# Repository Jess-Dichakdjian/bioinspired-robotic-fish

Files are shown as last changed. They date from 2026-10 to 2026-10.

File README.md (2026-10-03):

# PHOENIX — Bioinspired Robotic Fish

**Programmable Hybrid Oceanic Entity: Networked Inertial Explorer**

A physically built bioinspired robotic fish based on **Atlantic-mackerel carangiform locomotion**, combining a segmented mechanically actuated tail, waterproof 3D-printed structure, embedded sensing, closed-loop propulsion control, active head stabilization, hydrodynamic modelling, and experimental in-water validation.

> **Status:** Completed academic team project  
> **Team:** Abdelrhman Amgad, Ahmed Mounir, Giulia Di Sipio, Tony Al Helou, Jessica Dichakdjian  
> **Course:** Bioinspired Robotics Lab — Politecnico di Milano  
> **Academic Year:** 2025–2026

---

## At a Glance

| | |
|---|---|
| **Robot type** | Bioinspired robotic fish |
| **Biological inspiration** | Atlantic mackerel |
| **Locomotion** | Body-Caudal Fin (BCF), carangiform |
| **Propulsion** | Single DC motor driving a segmented tail |
| **Steering / stabilization** | Servo-actuated head |
| **Controller** | Arduino Nano |
| **Feedback** | Motor encoder + MPU-9250 IMU |
| **Control** | PID propulsion-speed loop + head stabilization |
| **Manufacturing** | SolidWorks, 3D printing, silicone molding, bent steel shaft |
| **Validation** | Dry tests, waterproofing, buoyancy, thrust measurement, swimming |
| **Final demonstrated speed** | 0.33 m/s at 1.5 Hz |
| **Normalized speed** | 0.73 body lengths/s |

---

# Project Overview

The goal of PHOENIX was to design, manufacture, integrate, and experimentally validate a **waterproof robotic fish capable of sustained straight-line swimming**.

The robot was inspired by Atlantic-mackerel propulsion and simplified into a practical electromechanical architecture suitable for rapid prototyping.

The complete engineering workflow covered:

```text
Biological Locomotion Study
            ↓
Kinematics & Hydrodynamic Modelling
            ↓
Mechanical Architecture
            ↓
CAD & Component Selection
            ↓
Manufacturing & Silicone Fabrication
            ↓
Electronics Integration
            ↓
Embedded Control
            ↓
Waterproofing & Buoyancy
            ↓
Experimental Validation
```

The final prototype successfully generated forward propulsion in water and integrated the mechanical, electronic, sensing, and control subsystems into a functional swimming robot.

---

# My Contributions

This was a **five-person team project**.

My contributions were concentrated in mechanical design, physical fabrication, integration, component selection, and experimental testing.

## Mechanical Design

I worked on the **mechanical design and CAD of the tail system**, including the segmented structure used to reproduce the required oscillatory swimming motion.

I also contributed to development of the propulsion mechanism that converts motor rotation into lateral tail oscillation.

## Manufacturing & Integration

My hands-on work included:

- 3D printing robot components
- mechanical assembly
- silicone molding
- manual bending of the drive shaft
- integration of the tail mechanism
- sealing and waterproofing
- general system integration and troubleshooting

## Electronics & Component Selection

I contributed to selecting and integrating components that had to satisfy two competing requirements:

- fit within the limited internal volume of the fish
- provide sufficient performance for underwater propulsion and sensing

I also assisted with the general electronics integration process.

## Experimental Testing

I participated in the full test programme, including:

- dry mechanical validation
- waterproofing tests
- buoyancy checks
- thrust measurement
- initial swimming trials
- final swimming validation

The embedded software, electronics, and system architecture were developed collaboratively by the team. Code in this repository is therefore presented as **team project code**, not as a claim of sole individual authorship.

---

# Biological Inspiration

PHOENIX was inspired by the **Atlantic mackerel**, selected for its efficient high-speed swimming characteristics.

The robot reproduces a simplified form of **Body-Caudal Fin carangiform locomotion**.

In carangiform swimming:

- most of the body remains relatively rigid
- oscillation is concentrated in the posterior section
- a travelling lateral wave propagates toward the tail
- the caudal fin generates the dominant propulsive force
- passive fins improve stability

---

# Mechanical Architecture

The robot consists of:

```text
Servo-Actuated Head
        ↓
Rigid Main Body
        ↓
Segmented Tail
        ↓
Active Tail Link
        ↓
Rigid Caudal Fin
```

The biological morphology was simplified into a mechanically realizable multi-link system while retaining the essential posterior-body oscillation required for carangiform propulsion.

### Final CAD Assembly

[▶ View final CAD assembly](P.H.O.E.N.I.X_Media/P.H.O.E.N.I.X_CAD/final_cad_assembly.mp4)

---

# Tail Propulsion Mechanism

The propulsion system uses a modified **Scotch-yoke / bent-shaft mechanism**.

```text
DC Motor
   ↓
Bent Shaft
   ↓
Oscillating Flapper / Linkage
   ↓
Segmented Tail Motion
   ↓
Caudal Fin
   ↓
Forward Thrust
```

A single rotating motor input is converted into lateral oscillation.

Mechanical stops and shaft geometry define the permitted angular motion of the tail links.

The architecture provides:

- high tail-beat frequency
- periodic oscillation
- single-actuator propulsion
- mechanically constrained link amplitudes

### Tail Mechanism

[▶ View tail mechanism](P.H.O.E.N.I.X_Media/P.H.O.E.N.I.X_CAD/tail_mechanism.mp4)

---

# Active Head Steering

The head is independently actuated by a servo motor.

Its role is to:

- compensate for heading drift
- improve straight-line stability
- provide active steering authority

The servo command is generated using IMU feedback in the stabilization loop.

---

# Fin Design

The robot includes:

- caudal fin
- dorsal fin
- anal fin
- two lateral fins

The **caudal fin** generates the primary propulsion force.

The remaining fins improve passive roll, yaw, and directional stability.

---

# Materials & Fabrication

The prototype combined rigid and compliant materials.

| Material | Application |
|---|---|
| PLA | External body and fins |
| ABS | Motor supports |
| Low-carbon steel | Bent drive shaft |
| Carbon fiber | Internal spar |
| Brass | Motor coupling |
| Ecoflex 00-10 | Tail and neck silicone sleeves |
| Elastic membrane | Additional waterproofing |

The manufacturing workflow included:

```text
CAD Design
    ↓
3D Printing
    ↓
Silicone Mold Fabrication
    ↓
Ecoflex Casting
    ↓
Steel Shaft Bending
    ↓
Mechanical Assembly
    ↓
Electronics Packaging
    ↓
Waterproofing
```

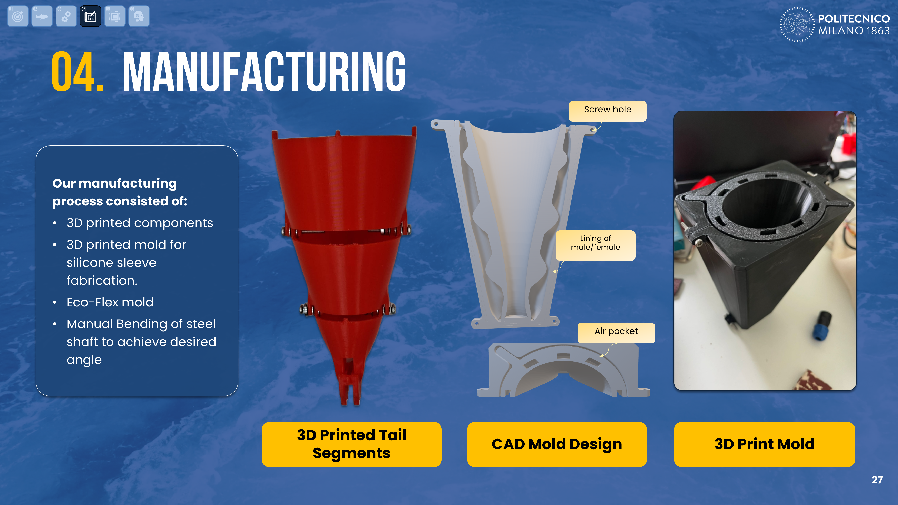
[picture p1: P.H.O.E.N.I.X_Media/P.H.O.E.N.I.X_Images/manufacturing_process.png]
Manufacturing process


---

# Waterproofing

Because the robot operates submerged, waterproofing was a major engineering constraint.

The final design used:

- enclosed electronics compartments
- silicone sleeves
- silicone adhesive
- protected shaft and cable interfaces
- iterative leak testing
- sealed mechanical interfaces

### Immersion / Leak Test

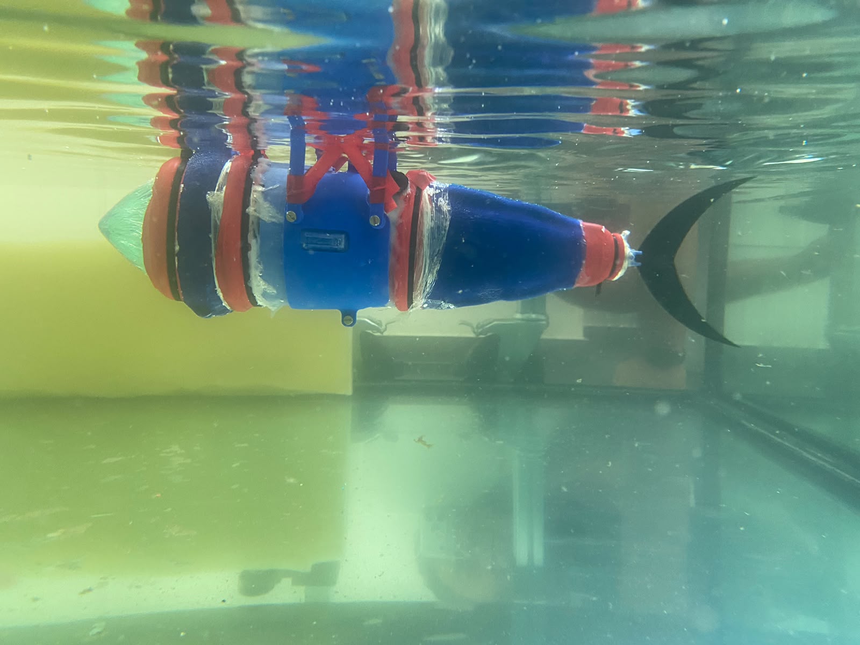
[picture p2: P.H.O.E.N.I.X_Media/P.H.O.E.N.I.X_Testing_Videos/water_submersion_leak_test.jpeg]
Water submersion test


---

# Buoyancy

The fish was tuned toward near-neutral buoyancy using:

- internal air volume
- component placement
- body mass
- steel ballast

Buoyancy was validated experimentally before powered swimming.

---

# Electronics Architecture

The embedded system includes:

- Arduino Nano
- brushed DC geared motor
- integrated encoder
- DRV8871 motor driver
- MPU-9250 IMU
- steering servo
- battery
- Hall-effect magnetic input

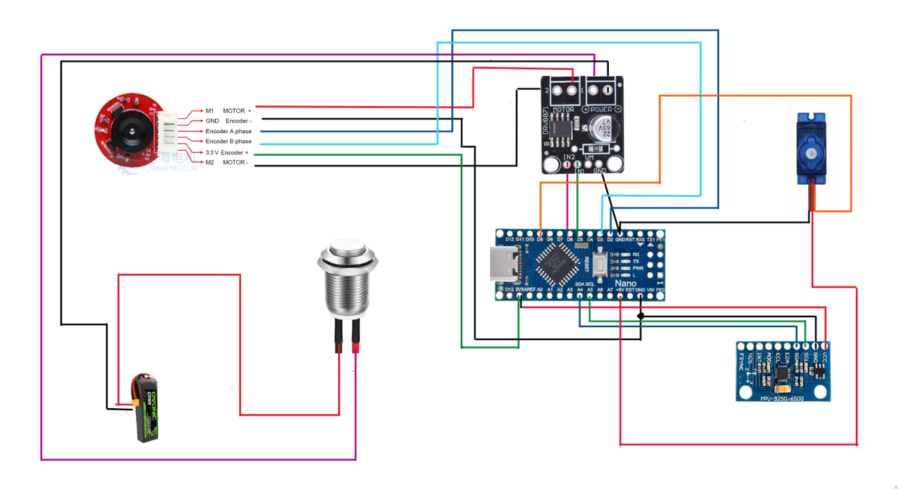
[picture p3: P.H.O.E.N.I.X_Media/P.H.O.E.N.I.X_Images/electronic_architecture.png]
Electronic architecture


### Internal Electronics Packaging

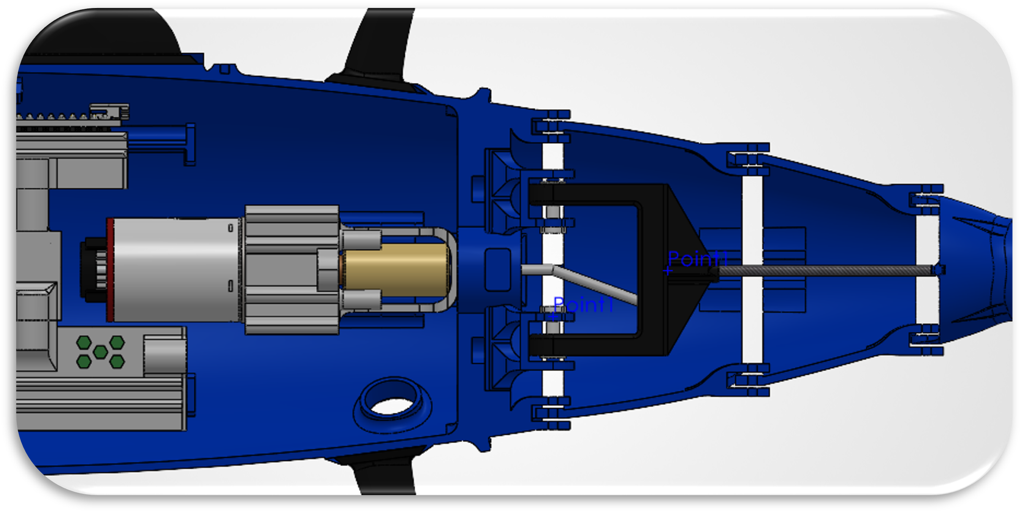
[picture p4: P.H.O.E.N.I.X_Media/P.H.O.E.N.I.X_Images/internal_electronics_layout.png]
Internal electronics layout


Component packaging was a significant design constraint because the electronics had to fit inside the waterproof body while preserving suitable mass distribution and buoyancy.

---

# Software Architecture

The embedded software contains several functional modules:

```text
Mode Manager
      ↓
Propulsion Controller
      ↓
PID Speed Control
      ↓
Motor Driver
      ↓
DC Motor
      ↑
Encoder Feedback

MPU-9250
      ↓
Drift Estimation
      ↓
Head Stabilization
      ↓
Servo Motor
```

The system supports:

- OFF mode
- normal swimming mode
- fast swimming mode
- soft-start ramp
- encoder-based PID speed control
- IMU-based drift estimation
- servo head correction
- magnetic external control

---

# Propulsion Control

Motor speed is regulated using encoder feedback:

```text
Target Frequency
      ↓
Soft-Start Ramp
      ↓
PID Controller
      ↓
PWM Command
      ↓
DRV8871
      ↓
DC Motor
      ↑
Encoder Feedback
```

Primary operating points were approximately:

```text
Normal mode: 1.5 Hz
Fast mode:   3.0 Hz
```

The soft-start stage reduces sudden mechanical loading during startup.

---

# Head Stabilization

The MPU-9250 gyroscope measures body rotation.

```text
Gyroscope
    ↓
Drift Estimate
    ↓
Servo Mapping
    ↓
Head Correction
```

The propulsion loop and the head-stabilization loop operate independently.

---

# Arduino Software

The final integrated robot software is available at:

```text
P.H.O.E.N.I.X_Software/
└── PHOENIX_CODE/
    └── PHOENIX_CODE.ino
```

The repository also preserves intermediate test software:

```text
Software_Used_During_Testing/
├── Calibration_Code/
├── Main_Logic_withPID/
└── Ramp_up/
```

These files document the development process rather than showing only the final result.

The project also contains a separate servo test program:

```text
P.H.O.E.N.I.X_Software/Servo/Servo.ino
```

---

# Kinematics & Hydrodynamic Modelling

The fish was represented using a rigid main body and a segmented multi-link tail.

The modelling work included:

- prescribed joint motion
- tail centerline reconstruction
- equivalent tail geometry
- hydrodynamic force estimation
- thrust prediction
- power estimation
- propulsive efficiency
- actuator sizing

A slender-body / added-mass-based hydrodynamic model was used to approximate the forces generated by the active tail.

The MATLAB model is available at:

```text
P.H.O.E.N.I.X_Software/
└── Dynamics Simulation/
    └── Dynamics_final.m
```

---

# Motor Sizing

The propulsion actuator was sized using:

- predicted hydrodynamic power
- required hydrodynamic torque
- drivetrain/mechanical efficiency
- silicone deformation losses
- safety margin

The final propulsion motor was a:

```text
ChiHai CHR-GM25-370ABHL
12 V brushed DC geared motor
350 RPM
Integrated incremental encoder
```

---

# Experimental Validation

Testing followed a progressive process to avoid exposing the final electronics to water before the mechanical system had been validated.

---

## 1. Dry Motion Test

The first validation stage checked:

- motor-driven tail actuation
- linkage motion through the silicone sleeve
- normal-speed mode
- fast-speed mode
- servo/head movement

[▶ Watch dry motion test](P.H.O.E.N.I.X_Media/P.H.O.E.N.I.X_Testing_Videos/dry_motion_test.mp4)

The expected oscillatory tail motion was achieved before water testing.

---

## 2. Waterproofing & Buoyancy

The robot was then submerged to validate:

- sealing
- sleeve integrity
- electronics isolation
- floating posture
- absence of visible leakage

This stage confirmed that the prototype was ready for powered aquatic testing.

---

## 3. Initial In-Water Trial

The first swimming test was performed without the final stabilizing fins.

[▶ Watch initial water trial](P.H.O.E.N.I.X_Media/P.H.O.E.N.I.X_Testing_Videos/initial_water_trial.mp4)

The robot generated forward propulsion, but directional stability was limited.

Observed roll and yaw motivated the addition of passive stabilizing fins before the final test.

---

# Thrust Measurement

A load-cell test was used to compare theoretical and experimental propulsion.

At **1.5 Hz**:

```text
Theoretical peak hydrodynamic thrust ≈ 1.20 N
Experimental peak dynamic load      ≈ 1.38 N
Difference                          ≈ 15%
```

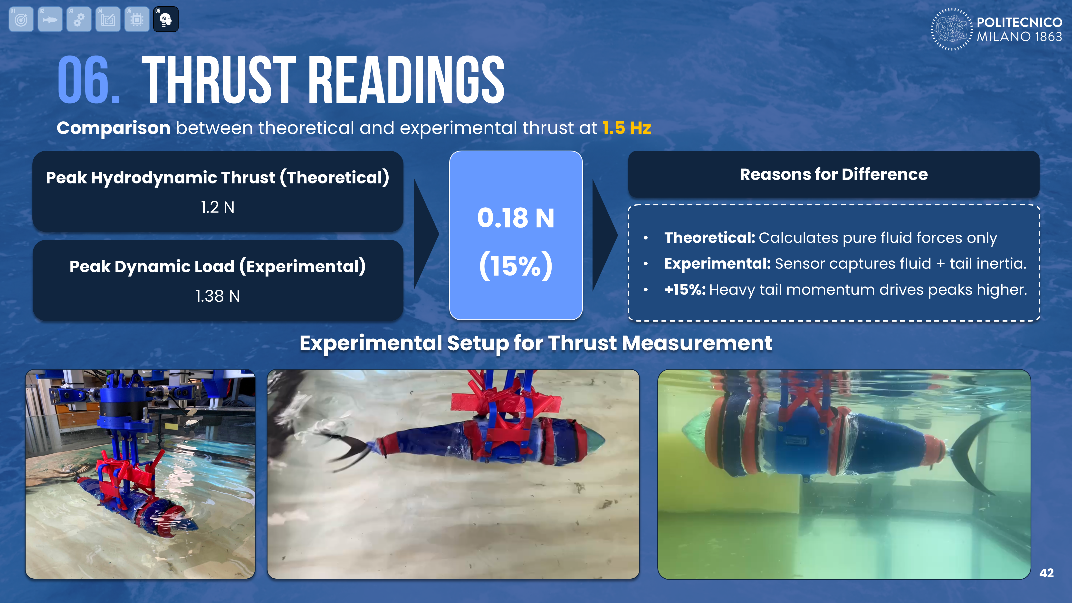
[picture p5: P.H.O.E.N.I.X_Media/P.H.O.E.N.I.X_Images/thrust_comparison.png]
Theoretical vs experimental thrust


### Physical Test

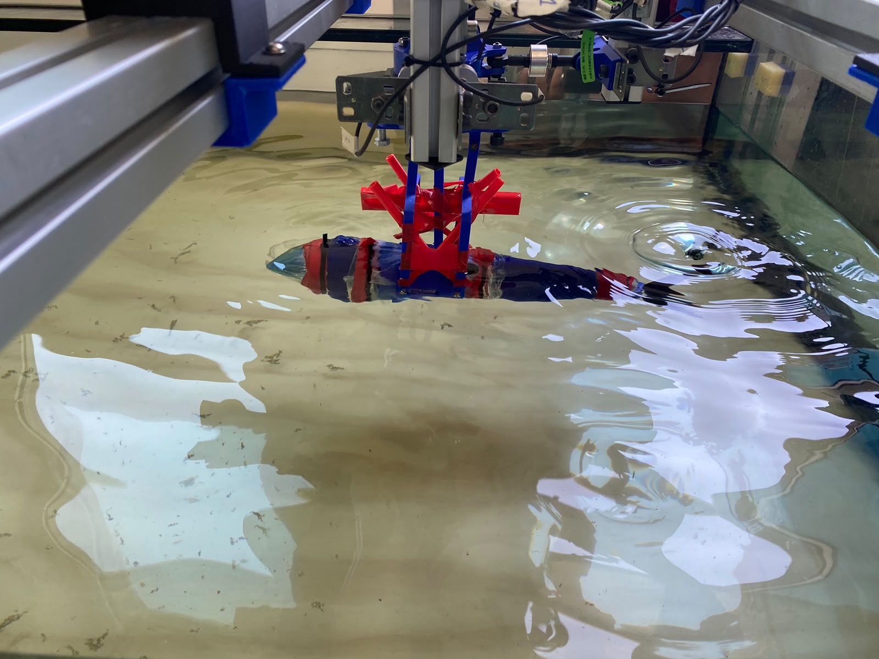
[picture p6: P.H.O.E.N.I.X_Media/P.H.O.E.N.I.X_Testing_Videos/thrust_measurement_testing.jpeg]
Thrust measurement setup


[▶ Watch thrust measurement](P.H.O.E.N.I.X_Media/P.H.O.E.N.I.X_Testing_Videos/thrust_measurement_testing.mp4)

The experimental value includes effects that are not fully represented in the simplified theoretical model, including:

- tail inertia
- linkage losses
- turbulence
- structural flexibility
- non-ideal tail motion

---

# Final Swimming Test

The complete robot was tested in water with the final stabilization configuration.

At:

```text
Tail frequency: 1.5 Hz
```

the prototype achieved:

```text
Swimming speed: 0.33 m/s
Normalized speed: 0.73 body lengths/s
```

[▶ Watch full swimming test](P.H.O.E.N.I.X_Media/P.H.O.E.N.I.X_Testing_Videos/full_swimming_test.mp4)

An additional underwater view of the propulsion behaviour is available here:

[▶ Underwater propulsion view](P.H.O.E.N.I.X_Media/P.H.O.E.N.I.X_Testing_Videos/underwater_pov_swimming_thurst_tester.mp4)

---

# Final Course Competition

At the end of the project, the teams participated in a class swimming comparison.

Each group performed a single tank-traversal trial, with performance evaluated using swimming time and body-length normalization.

**PHOENIX recorded the fastest body-length-normalized traversal among the participating group robots in that single-run comparison.**

Because each team performed only one trial, this result is presented as a **course demonstration result**, not as a statistically validated benchmark.

[▶ Watch competition swim](P.H.O.E.N.I.X_Media/competition_final_swim.mp4)

---

# Engineering Iteration

The project archive intentionally preserves earlier design iterations.

The mechanical system evolved through changes related to:

- friction
- tail geometry
- waterproofing
- electronics packaging
- assembly access
- directional stability
- actuator integration

This repository therefore documents not just the final robot, but also the engineering process used to reach it.

---

# Repository Structure

```text
bioinspired-robotic-fish/
│
├── README.md
│
├── P.H.O.E.N.I.X_CAD/
│   ├── P.H.O.E.N.I.X.SLDASM
│   ├── Tail_Links_Assembly.SLDASM
│   ├── Body_V3.SLDPRT
│   ├── Link3.SLDPRT
│   ├── Link4.SLDPRT
│   ├── Link5_V3.SLDPRT
│   └── ...
│
├── P.H.O.E.N.I.X_Software/
│   ├── Dynamics Simulation/
│   │   └── Dynamics_final.m
│   │
│   ├── PHOENIX_CODE/
│   │   └── PHOENIX_CODE.ino
│   │
│   ├── Servo/
│   │   └── Servo.ino
│   │
│   └── Software_Used_During_Testing/
│       ├── Calibration_Code/
│       ├── Main_Logic_withPID/
│       └── Ramp_up/
│
├── P.H.O.E.N.I.X_Media/
│   ├── P.H.O.E.N.I.X_CAD/
│   ├── P.H.O.E.N.I.X_Images/
│   ├── P.H.O.E.N.I.X_Testing_Videos/
│   └── competition_final_swim.mp4
│
└── P.H.O.E.N.I.X_Doc/
    └── Bioinspired Robotics Lab Project Presentation_vf-compressed.pdf
```

---

# Limitations

The prototype achieved the primary project objective, but several limitations remain:

- swimming experiments were performed in a controlled tank environment
- the hydrodynamic model uses simplifying assumptions
- tail-fluid interaction is difficult to represent exactly
- long-duration waterproofing was not characterized
- steering and trajectory tracking remain relatively simple
- full autonomous navigation was outside the project scope
- the final competition comparison used only one trial per team

---

# Future Work

Potential improvements include:

- vision-based navigation
- closed-loop trajectory tracking
- active depth control
- optimized tail geometry
- improved hydrodynamic modelling
- improved waterproofing durability
- reduced drivetrain losses
- energy-efficiency analysis
- longer-duration endurance tests
- autonomous underwater navigation

---

# Skills Demonstrated

This project provides evidence of experience in:

- bioinspired robotics
- underwater robotics
- robotic locomotion
- mechatronics
- SolidWorks
- CAD
- 3D printing
- silicone molding
- waterproof mechanical design
- electromechanical integration
- actuator selection
- Arduino
- embedded systems
- PID control
- encoder feedback
- IMU sensing
- servo control
- MATLAB
- hydrodynamic modelling
- dynamics
- motor sizing
- experimental robotics
- thrust measurement
- iterative prototyping
- system integration
- hardware testing

---

# Team Work & Attribution

PHOENIX was developed as a **five-person academic team project**.

The robot, software, CAD, electronics, and experimental programme were developed collaboratively.

My primary contributions were:

- mechanical CAD and design of the tail system
- development and physical implementation of the propulsion mechanism
- 3D printing
- silicone molding
- shaft bending
- mechanical assembly
- sealing and waterproofing
- electronics/component selection and packaging
- system integration
- experimental testing

Software and system-level code are presented as team project work unless explicitly stated otherwise.

---

# Project Status

✅ **Completed functional underwater robotic prototype**

The final system demonstrated:

- waterproof operation
- stable deployment
- oscillatory tail propulsion
- closed-loop propulsion-speed control
- IMU-based head stabilization
- experimentally measured thrust
- straight-line swimming
- 0.33 m/s swimming speed at 1.5 Hz
- successful final course competition run

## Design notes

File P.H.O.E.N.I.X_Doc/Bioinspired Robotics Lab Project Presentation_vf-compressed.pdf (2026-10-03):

# P.H.O.E.N.I

.X

Abdelrhman Amgad, Ahmed Mounir, Giulia Di Sipio, Tony Al Helou, Jessica Dichakdjian

Bioinspired Robotics Lab | A.Y. 2025-26 Professor Giovanni Bianchi

# Programmable Hybrid Oceanic Entity: Networked Inertial explorer

1

# OUTLINE

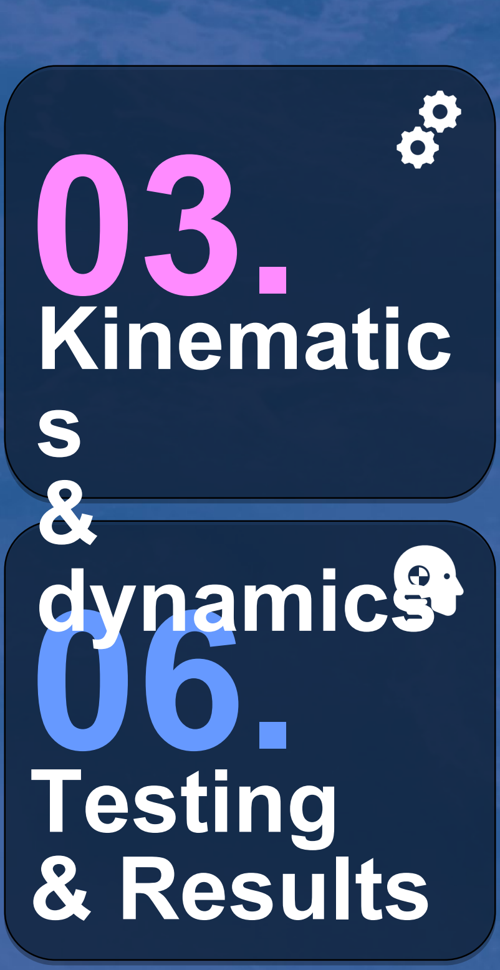
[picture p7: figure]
06. Testing & Results; 03. Kinematic s&; dynamics

2

05.

# Electroni

cs

# & control

04.

# Robotic Fish Design

02.

# Bioinspir ation

01.

# introduct ion

01.
introduct ion | 3

Bioinspired Design | Testing & Validation | Results and Discussion

# Motivation of the Project

o

## 1. Goal

### Design and fabricate a prototype of a waterproof, buoyant robotic fish capable of sustained straight-line swimming

- Replicate high-speed and efficient propulsion of
Atlantic Mackerel fish
- Carangiform (Body-Caudal Fin) locomotion
- Submerge in a controlled aquatic environment
- Experimentally test the
robot's swimming speed
and thrust generation
- Compare experimental
results with theoretical
models
- Identify hydrodynamic and structural design limitations

4

01 | 02 | 03 | 04 | 05 | 06

# o1Why a Robotic Fish?

A bioinspired robotic fish supports marine research and inspection in a non-intrusive manner

5

- Minimal acoustic and wake signatures compared to
- Navigate and inspect environments and infrastructure
- Monitor coral reefs, water quality, pipelines
- Support marine research and aquaculture operations without

# Design Constraints & Requirements

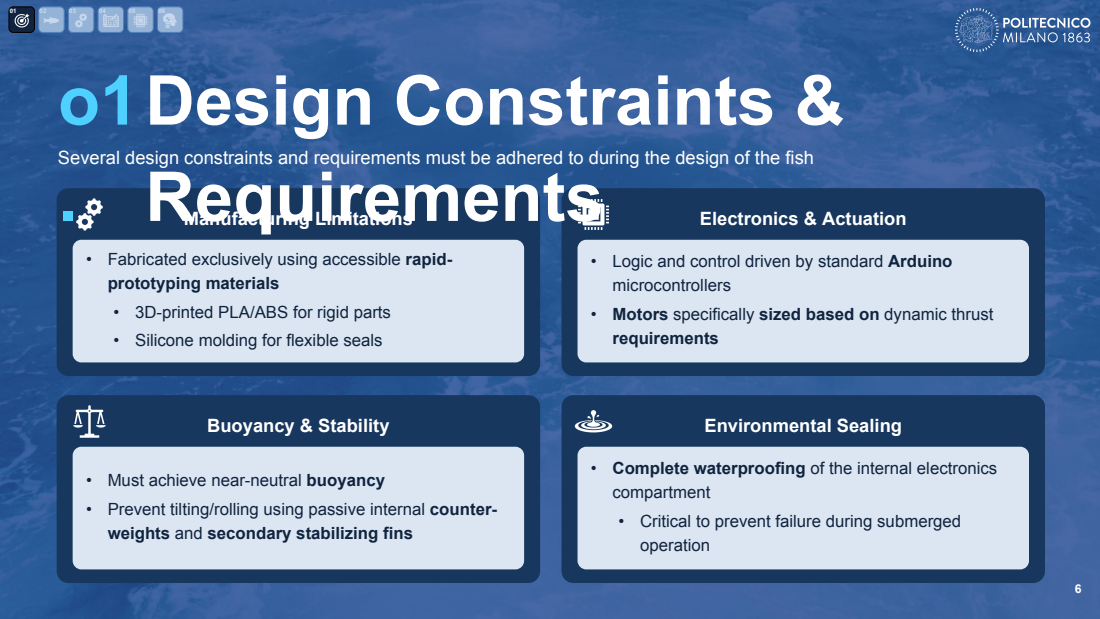
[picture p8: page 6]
Manufacturing Limitations; Electronics & Actuation; Buoyancy & Stability; Environmental Sealing

Several design constraints and requirements must be adhered to during the design of the fish

• Fabricated exclusively using accessible rapid-
prototyping materials
• 3D-printed PLA/ABS for rigid parts
• Silicone molding for flexible seals

• Logic and control driven by standard Arduino
microcontrollers
• Motors specifically sized based on dynamic thrust
requirements

• Complete waterproofing of the internal electronics
compartment
• Critical to prevent failure during submerged
operation

• Must achieve near-neutral buoyancy
• Prevent tilting/rolling using passive internal counter-
weights and secondary stabilizing fins

02.
bioinspiratio n | 7

# Biological Inspiration of Robot

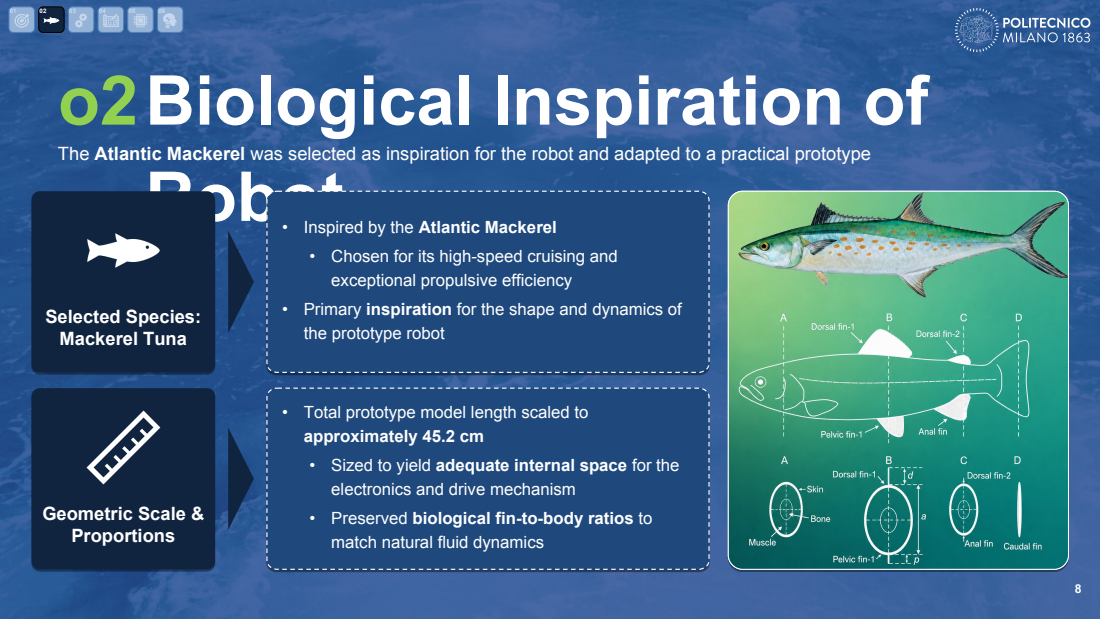
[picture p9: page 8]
Selected Species: Mackerel Tuna; Geometric Scale & Proportions

The Atlantic Mackerel was selected as inspiration for the robot and adapted to a practical prototype

• Inspired by the Atlantic Mackerel
• Chosen for its high-speed cruising and
exceptional propulsive efficiency
• Primary inspiration for the shape and dynamics of
the prototype robot

• Total prototype model length scaled to
approximately 45.2 cm
• Sized to yield adequate internal space for the
electronics and drive mechanism
• Preserved biological fin-to-body ratios to
match natural fluid dynamics

9

# o2Locomotion Strategy

The fish utilizes a BCF Carangiform locomotion strategy for thrust generation, steering, and stability
- Synchronized action of posterior body undulations and tail movements
- Combines side-to-side sweeping of fin (heaving) with angular twisting (pitching)
- Pushes water backward to generate a positive net forward force and overcome hydrodynamic drag
- Bending motion is strictly localized to the posterior section of the fish
- Kinematic wave actions are confined to the rear third of the total body length
- This tail structure and movement strategy generates a smooth traveling wave
- Stiff, lunate-shaped caudal fin designed for optimized thrust transmission
- Passive secondary fins handle orientation (pectoral) and lateral stability control (dorsal/pelvic)
Thrust Generation | Undulatory Wave
Profile | Hydrodynamic Fins

Body-Caudal Fin (BCF) Carangiform Swimming

10

# From Biology to

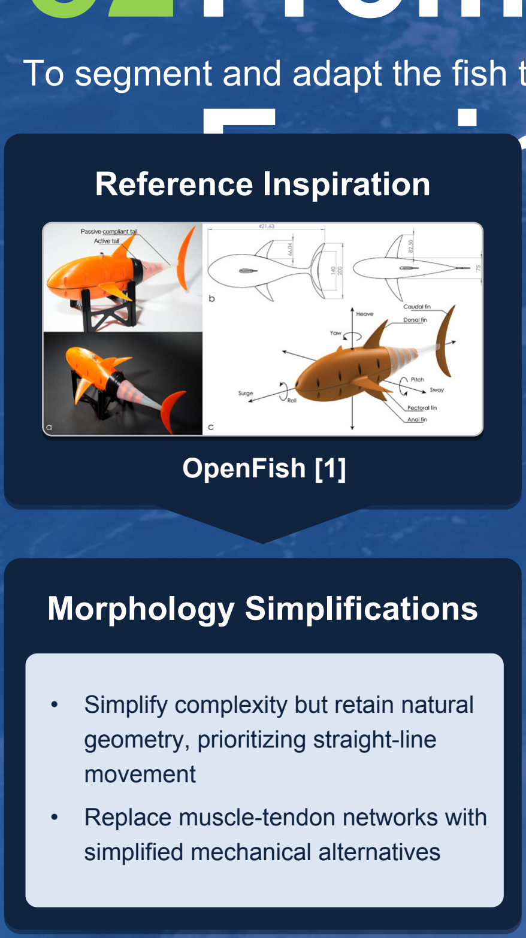
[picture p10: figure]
Morphology Simplifications; Reference Inspiration; geometry, prioritizing straight-line movement • Replace muscle-tendon networks with simplified mechanical alternatives; OpenFish [1]

# Engineering

o2

To segment and adapt the fish to a robot, several simplifications were made to the morphology of the fish Structure Segmentation

Static Body
Rigid central compartment containing and protecting the primary electronics, Arduino, and battery
Passive Tail
Flexible, segmented multi-link jointed portion of the tail propagating the undulatory traveling wave
Active Tail
Final tail linkage connected directly to the main motor drive mechanism to receive active mechanical power
Rigid Caudal Fin
Solid lunate-shaped profile attached to the active tail segment to for force transmission and forward propulsion
- Simplify complexity but retain natural

Active Head
Rigid section at anterior tip driven by an independent servo motor to handle active steering and heading control

# o2Actuation Inspiration

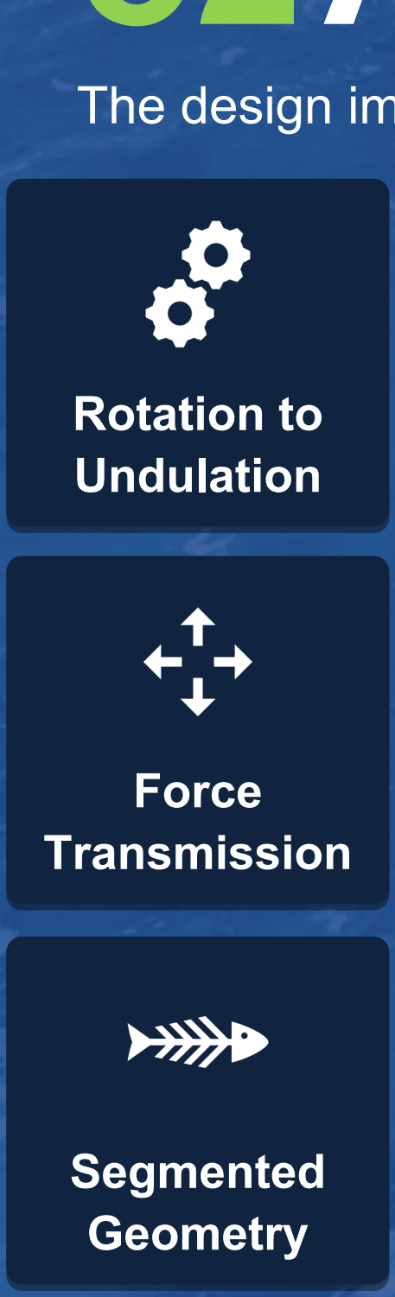
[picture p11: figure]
Segmented Geometry; Rotation to Undulation; Transmission

The design implements a linkage mechanism to convert a motor's rotation into a propulsive traveling wave

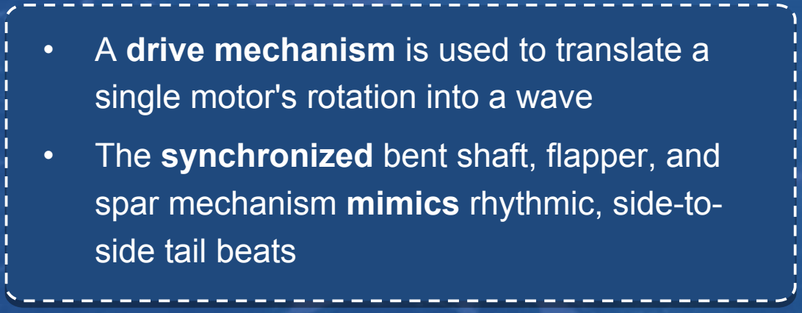
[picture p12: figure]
single motor's rotation into a wave; spar mechanism mimics rhythmic, side-to- side tail beats
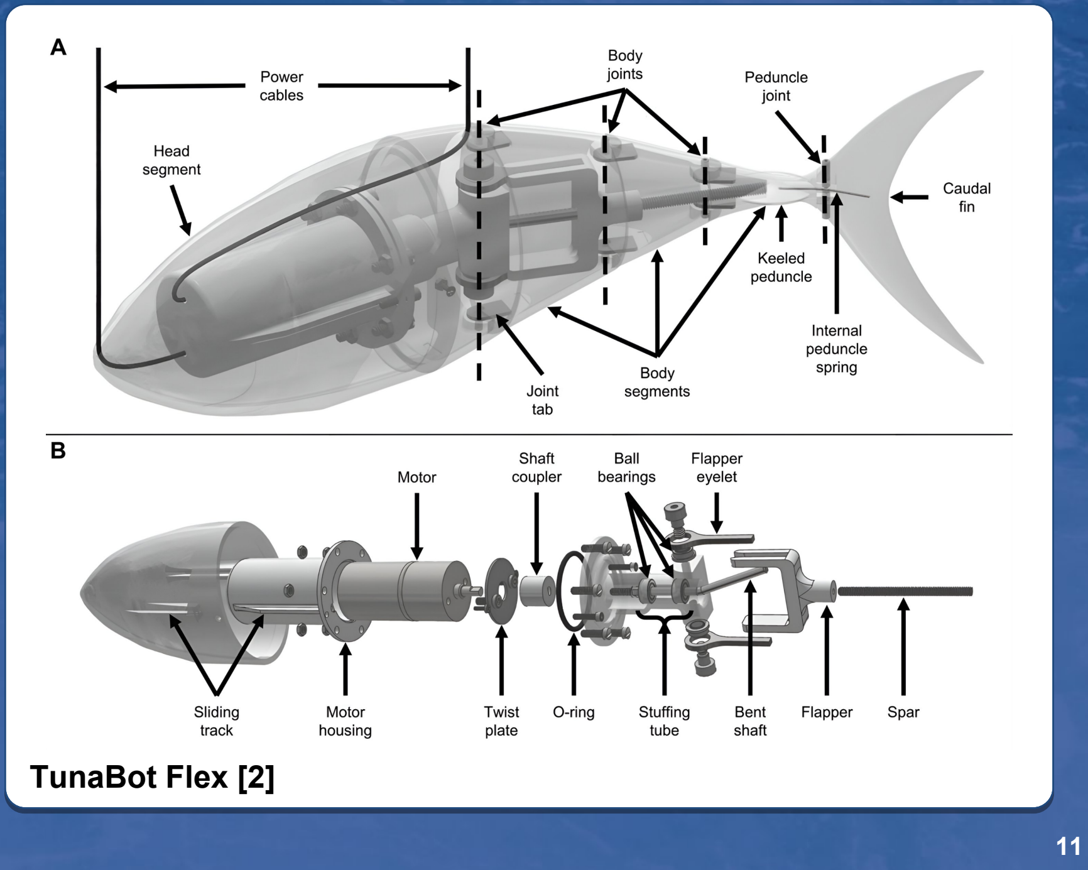
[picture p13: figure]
TunaBot Flex [2]

- Replaced complex muscles with a single-axis, convert the single input into lateral body
- A drive mechanism is used to translate a
- The synchronized bent shaft, flapper, and
- The drive mechanism consists of an internal rigid spar, which channels actuation force directly to the caudal fin to generate thrust
- Passive tail segments follow smoothly Force

03.

# kinematics &dynamics

12

13

# o3Kinematic model

# Motion law & Strouhal

o3

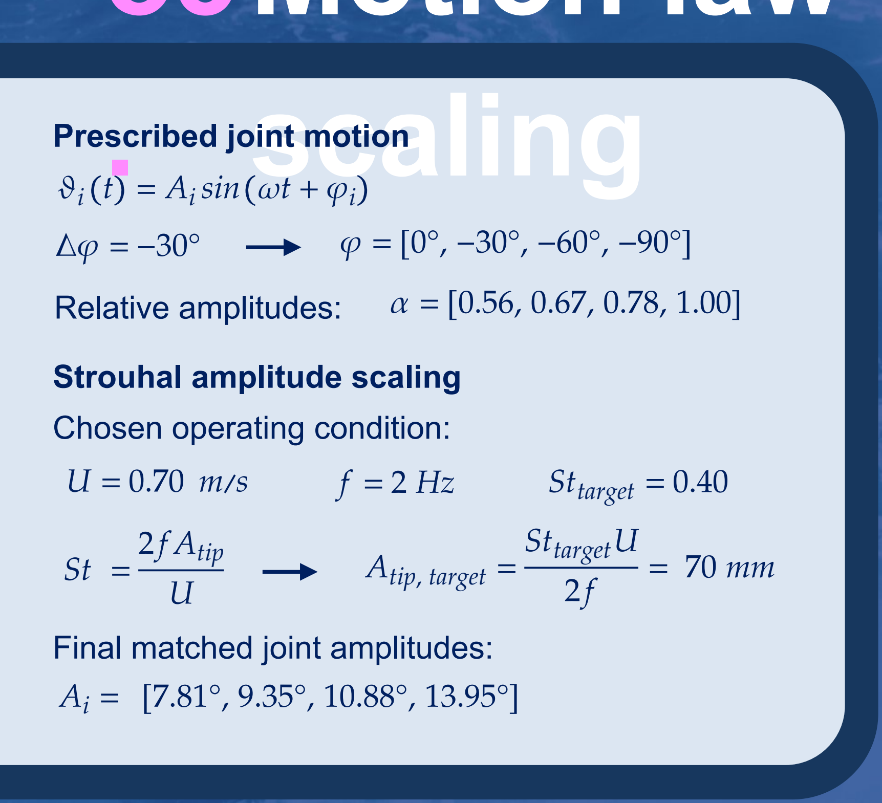
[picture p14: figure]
scaling; Prescribed joint motion; sin ωt + φi; Strouhal amplitude scaling Chosen operating condition:; Sttarget = 0.40; 2fAtip U; Atip, target =; SttargetU 2f; Final matched joint amplitudes:; Relative amplitudes:

# o3Centerline reconstruction

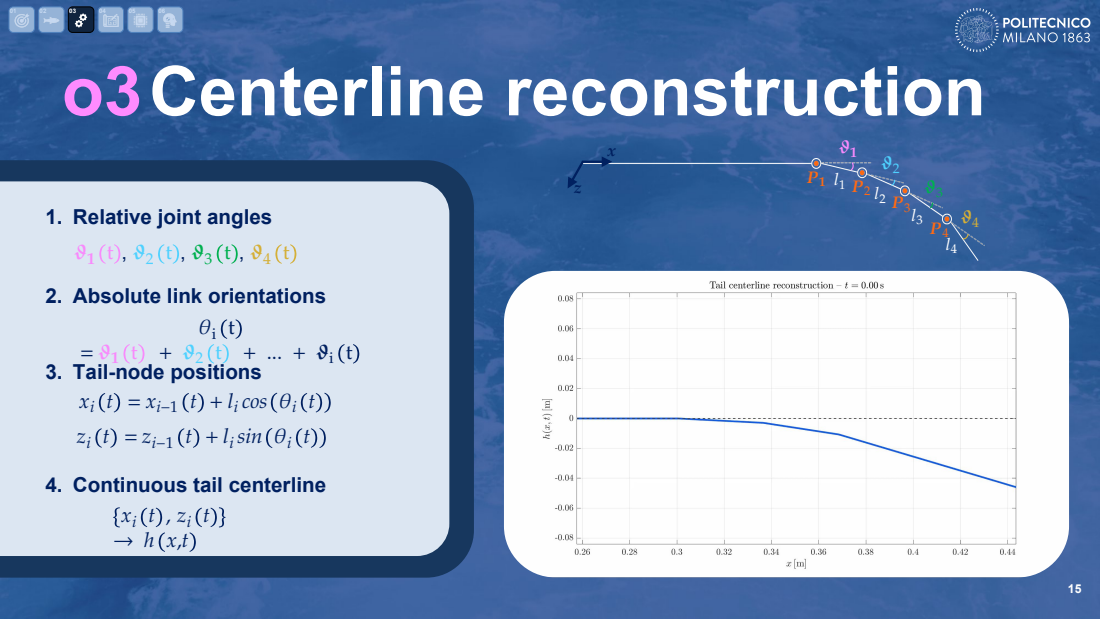
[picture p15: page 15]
cos θi; sin θi

1. Relative joint angles
2. Absolute link orientations

3. Tail-node positions

4. Continuous tail centerline

# o3Tail hydrodynamics

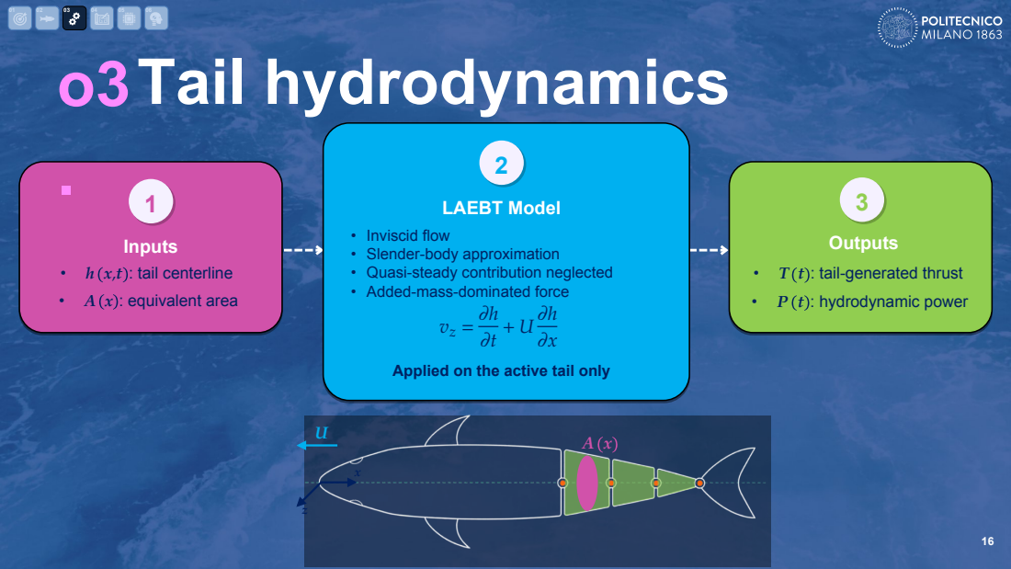
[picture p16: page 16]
Inputs; • h x,t : tail centerline • A x : equivalent area; 2 LAEBT Model

Outputs
• T t : tail-generated thrust
• P t : hydrodynamic power

• Inviscid flow
• Slender-body approximation
• Quasi-steady contribution neglected
• Added-mass-dominated force

Applied on the active tail only

# o3Equivalent tail geometry

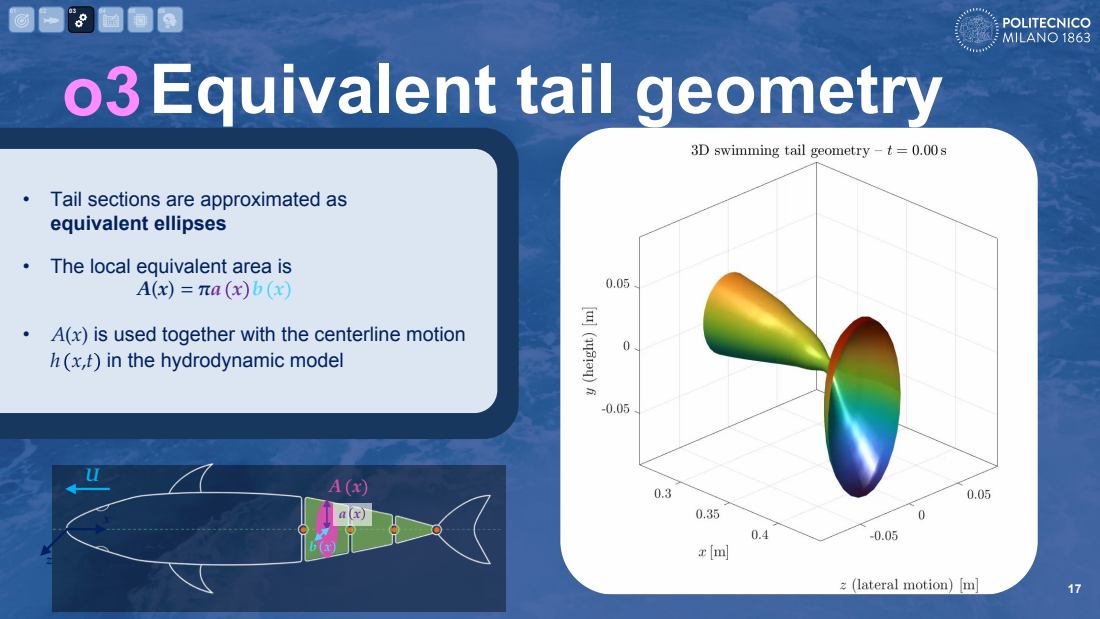
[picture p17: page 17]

• Tail sections are approximated as
equivalent ellipses
• The local equivalent area is
• A(x) is used together with the centerline motion
ℎ x,t in the hydrodynamic model

# o3Thrust, power & efficiency

18

04.

# Robotic Fish design 19

# Simplifying Fish Morphology

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
P1 P2
P3
P4

z

x

We simplified the fish’s morphology as shown in the Kinematics section to a structure made of a series of links. We have the head link, body link, three tail links and the caudal fin.

# o4The Core Mechanism

21

We use a version of the scotch-yoke mechanism. We have a single motor actuation with a bent shaft fitted in a slot providing oscillatory motion.

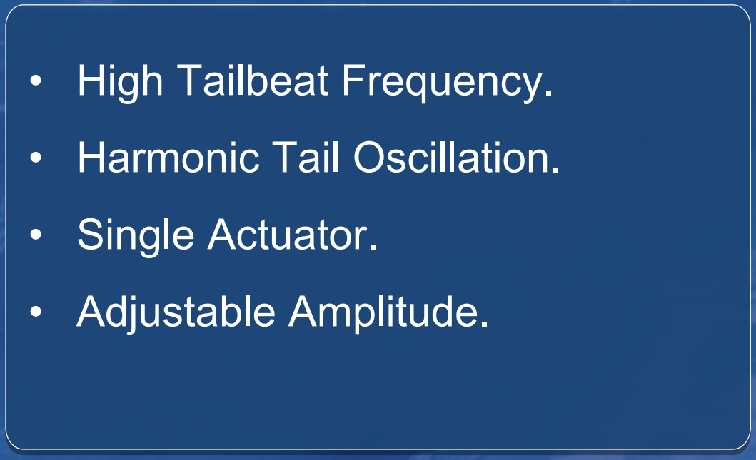
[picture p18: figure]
• High Tailbeat Frequency. • Harmonic Tail Oscillation. • Single Actuator. • Adjustable Amplitude.

# o4Controlling the Amplitude

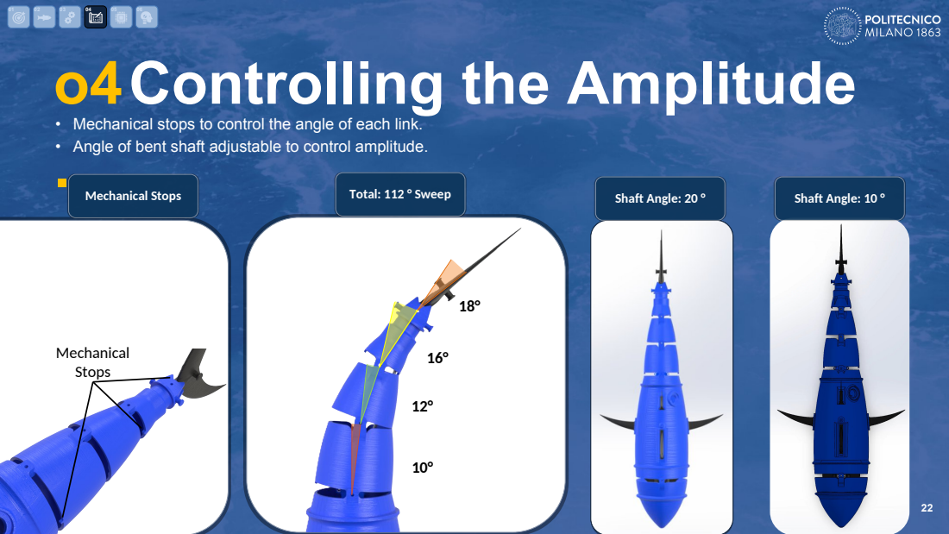
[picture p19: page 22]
Mechanical Stops; Total: 112 ° Sweep Mechanical Stops; Shaft Angle: 20 °; Shaft Angle: 10 °

• Mechanical stops to control the angle of each link.
• Angle of bent shaft adjustable to control amplitude.

# o4The Head Mechanism

23

We actuate the head to turn from side to side, and to ensure
swimming in a straight-line if needed.
To do this we have a servo motor fixed in the body and connected via a flat horn to rotate the head.

# o4Fin Design

02 | 03 | 04 | 05 | 06

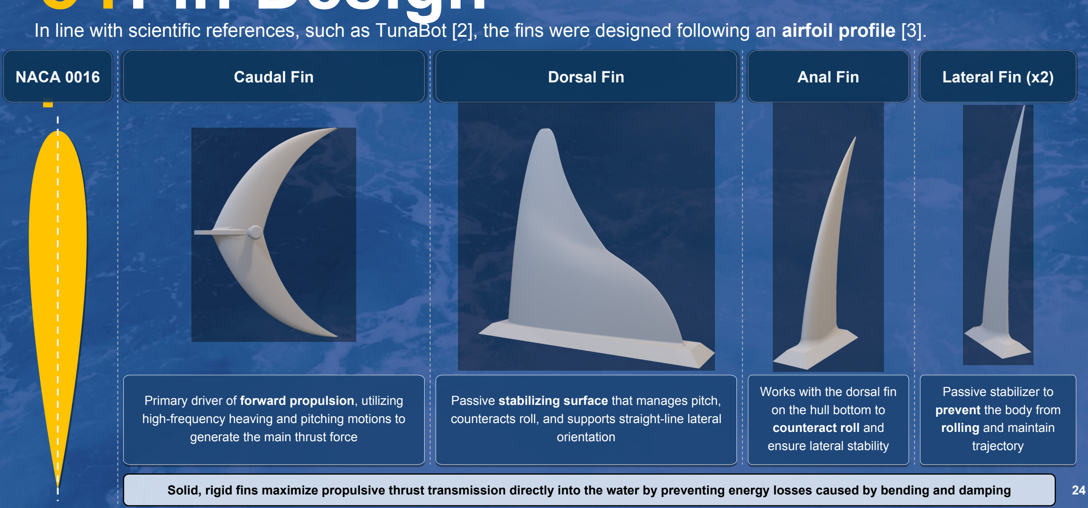
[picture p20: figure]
NACA 0016; Caudal Fin; Dorsal Fin; Anal Fin; Lateral Fin (x2); generate the main thrust force; orientation; Works with the dorsal fin on the hull bottom to counteract roll and ensure lateral stability; Passive stabilizer to prevent the body from rolling and maintain trajectory

In line with scientific references, such as TunaBot [2], the fins were designed following an airfoil profile [3].

01

Solid, rigid fins maximize propulsive thrust transmission directly into the water by preventing energy losses caused by bending and damping

Primary driver of forward propulsion, utilizing
high-frequency heaving and pitching motions to

Passive stabilizing surface that manages pitch, counteracts roll, and supports straight-line lateral

# Component Sizing and Selection

o4

25

Component | Selection Criteria
DC Motor | High torque-to-weight ratio, Integrated encoder, Optimal gear reduction, Compact
Battery | Appropriate operating voltage, High energy density (Ah/g), Compact form factor
Servo Motor | Adequate stall torque, Fast actuation speed, Precise angular resolution
Electronics | Processing speed, Current rating, Sensor accuracy, I/O pins

# o4Material Selection

26

Material | Components | Reason
PLA | External body, Fins | Lightweight, easy to print, good stiffness
ABS | Motor Supports | Higher strength and impact resistance
Low-Carbon Steel | Bent Shaft | Ductile, high fatigue resistance
Carbon Fiber | Spar | High stiffness-to-weight ratio
Brass | Motor Coupling | Corrosion resistant, easily machined
Ecoflex 00-10 Silicone | Tail and Neck Sleeve | Waterproof, high elasticity seal
Elastic Latex Membrane | Tail and Neck waterproofing | Extra waterproofing

# o4Manufacturing

27

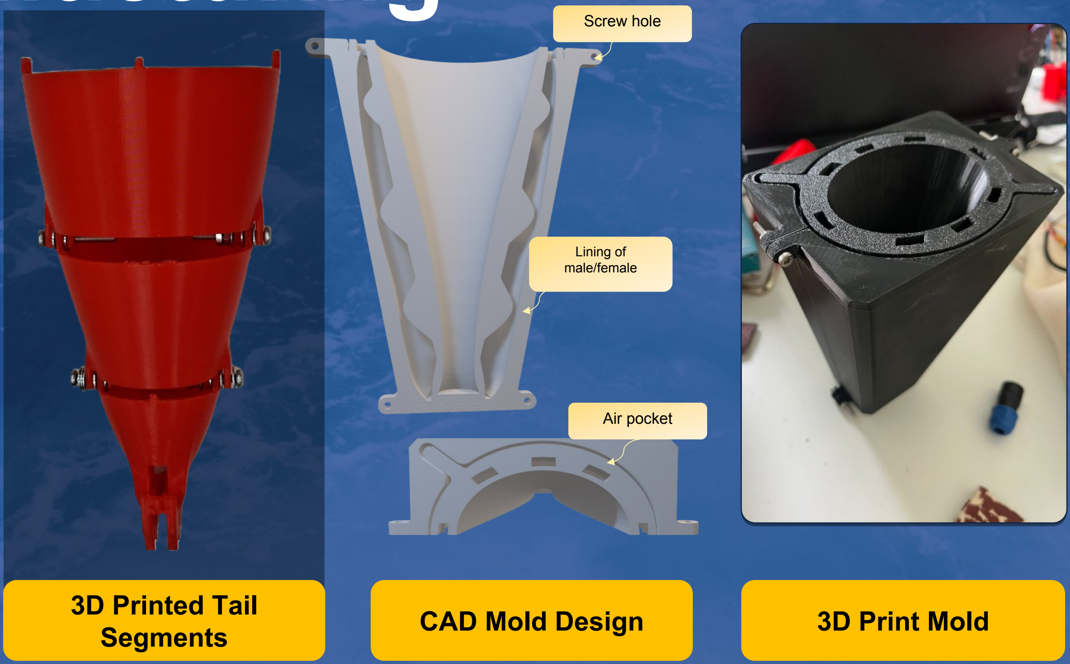
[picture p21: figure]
CAD Mold Design; 3D Print Mold; Air pocket; Screw hole; Lining of male/female; 3D Printed Tail Segments
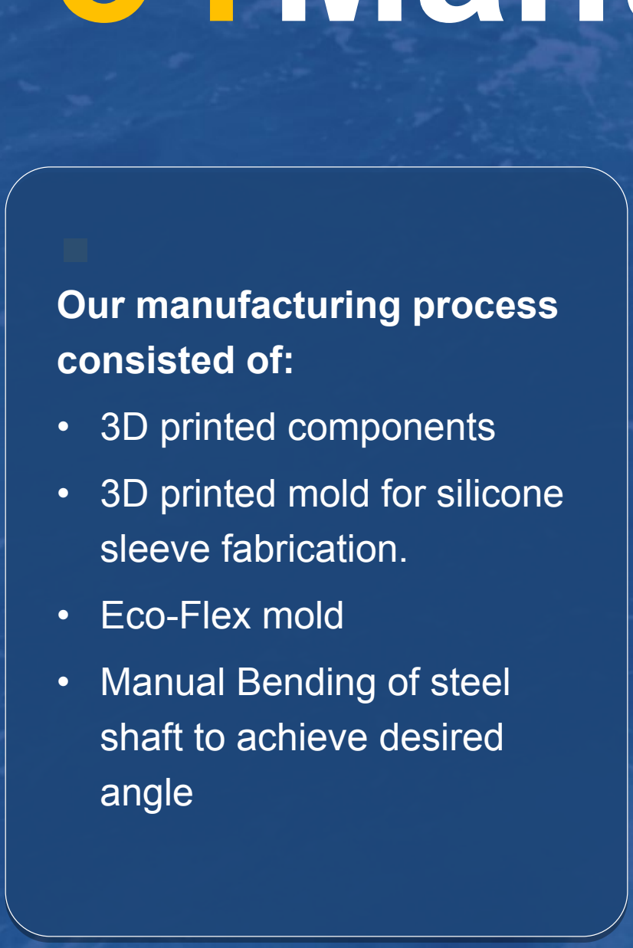
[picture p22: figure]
Our manufacturing process consisted of: • 3D printed components • 3D printed mold for silicone sleeve fabrication. • Eco-Flex mold • Manual Bending of steel shaft to achieve desired angle

# Waterproofing Strategy & Validation

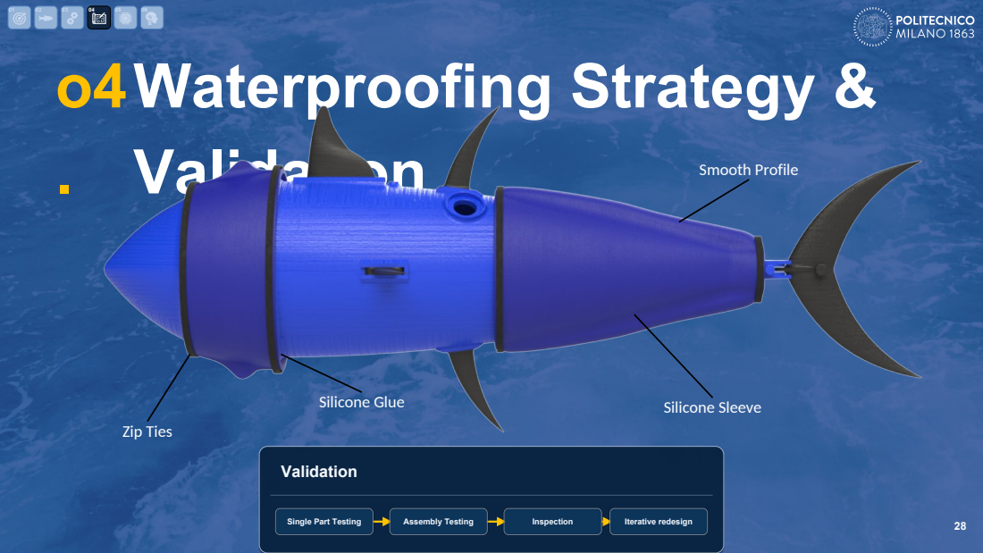
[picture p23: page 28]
Validation; Single Part Testing; Assembly Testing; Inspection; Iterative redesign; Zip Ties; Silicone Sleeve; Smooth Profile; Silicone Glue

# o4Buoyancy

29

To achieve a neutrally-buoyant fish we incorporate:
- Enclosed design providing internal air volume

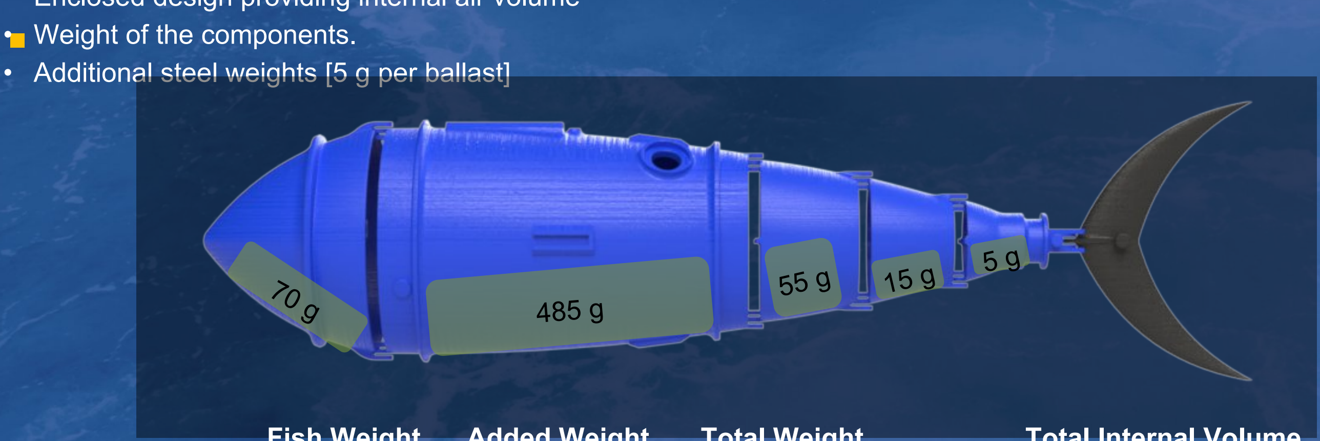
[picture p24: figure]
• Weight of the components.

- Additional steel weights [5 g per ballast]
Fish Weight Added Weight Total Weight | Total Internal Volume
750 g | 780 g | 1530 g | 901.7 cm³

# o4Assembly and integration

30

05.

# electronics & control

31

# o5Electronic architecture

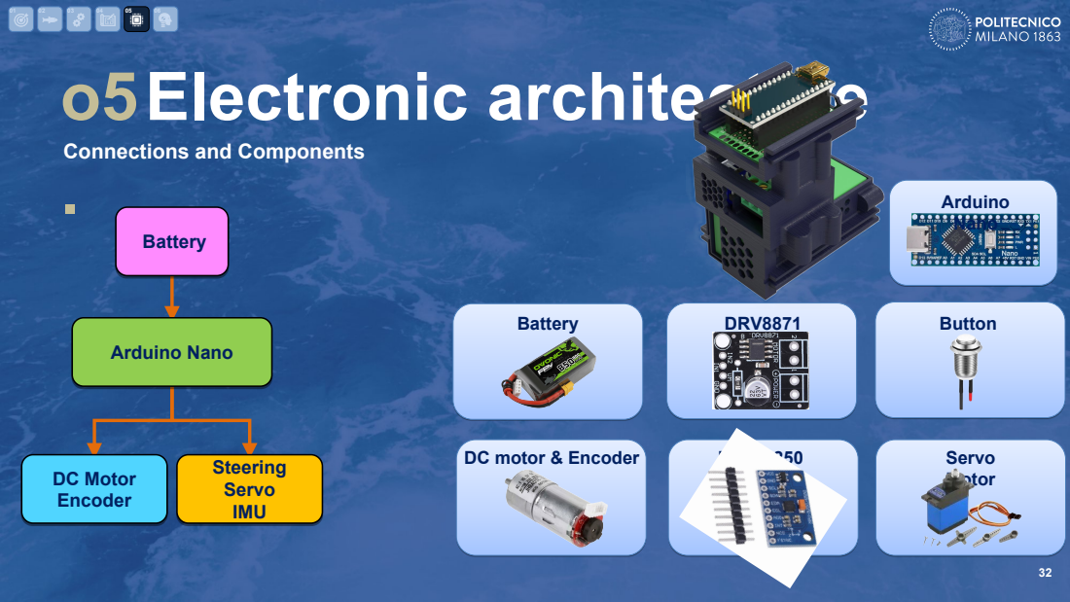
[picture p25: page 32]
Arduino Nano; DRV8871; Button; DC motor & Encoder; MPU-9250; Servo; Motor; Battery; DC Motor Encoder; Steering Servo IMU

Connections and Components

33

Motor Type | Brushed DC Geared Motor with Encoder
Nominal Voltage | 12 V
Rated Speed | 350 RPM
Mass | 110 g
Output Current | 60-200 mA
Diameter | 25 mm
Integrated Encoder | Yes

Actuation system
- Motor: ChiHai CHR-GM25-370ABHL Brushed DC Motor (12 V, 350 RPM)
- Gearbox: Integrated GM25 Reduction Gearbox
- Encoder: Integrated Incremental Encoder (CHR-GM25-370ABHL Series)

# Motor Selection &

o5
τpeak, ℎyd = 0.35 Nm | peak hydrodynamic torque
Kloss = 1.20 | silicone losses
SF = 1.20 | safety margin
Preq = SF∙Kloss∙Ppeak, ℎyd = 6.36 W | required motor power
τreq = SF∙Kloss∙τpeak, ℎyd = 0.51 N | required motor torque

Pmean,
power

# o5System Circuit

34

35

## Modules

Mode Manager
- OFF/ Normal/ Fast modes
- Magnetic tap/ hold detection Propulsion Controller
- Soft-start ramp
- PID motor speed control
- PWM motor command
Feedback Module
- Encoder speed acquisition
- IMU gyro acquisition
Steering Controller
- Drift angle selection
- Servo head correction

# o5Software architecture

# o5Machine control

36

Finite-state machine for switching between normal and fast propulsion modes.

States
- OFF
- Loading Normal Mode
- Normal Swimming
- Loading Fast Mode
- Fast Swimming
Events
- Short magnetic tap
- Long magnetic hold ≥ 3 s
- Soft-start complete
- Short magnetic tap while swimming
- Magnetic tap during loading

37

# Closed-Loop Control System

o5
Arduino-based control of propulsion and head stabilization.

PROPULSION SPEED LOOP
Updates every 50 ms
Control Summary
Control loops
- Propulsion speed loop
- Head stabilization loop
Sensors
- Encoder: motor speed
- MPU9250: body rotation
Actuators
- DC motor via PWM
- Servo head correction

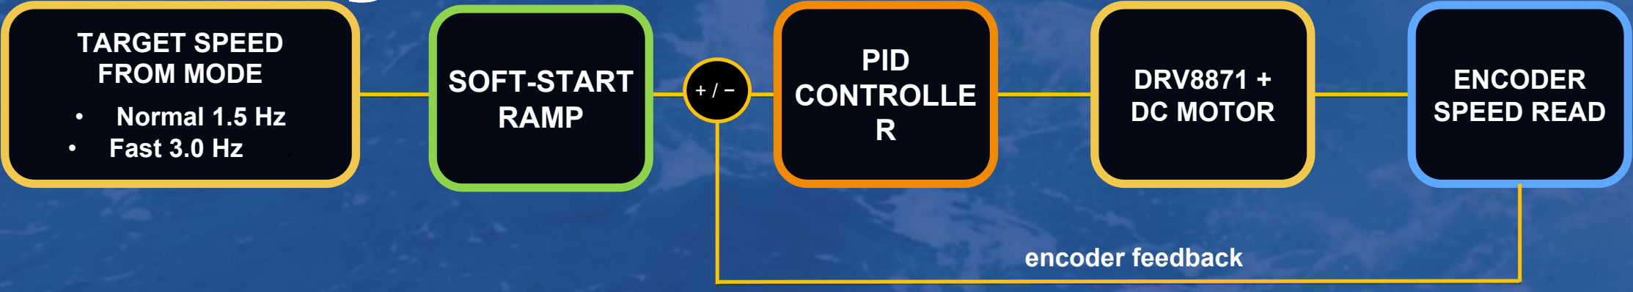
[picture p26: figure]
encoder feedback; TARGET SPEED FROM MODE • Normal 1.5 Hz • Fast 3.0 Hz .; SOFT-START RAMP; PID CONTROLLE R; DRV8871 + DC MOTOR; ENCODER SPEED READ

The Arduino code keeps the selected swimming frequency stable while independently correcting body drift through the servo head.

06.

# testing & RESults

38

39

01 | 02 | 03 | 04 | 05

# o6Dry Motion VALIDATION

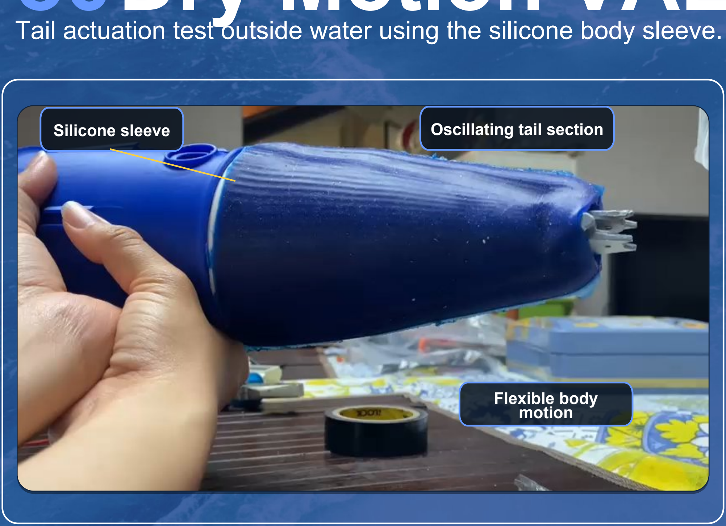
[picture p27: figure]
Silicone sleeve; Oscillating tail section; Flexible body motion

Tail actuation test outside water using the silicone body sleeve.

06

Test objective
Validate the mechanical transmission and tail oscillation before water exposure.
Verified functions
- Motor-driven tail actuation
- Linkage motion inside silicone sleeve
- Normal and fast mode response
- Servo/head movement
Result
Expected oscillatory tail motion was achieved in air.

40

01 | 02 | 03 | 04 | 05

# Waterproofing & Buoyancy

o6

06

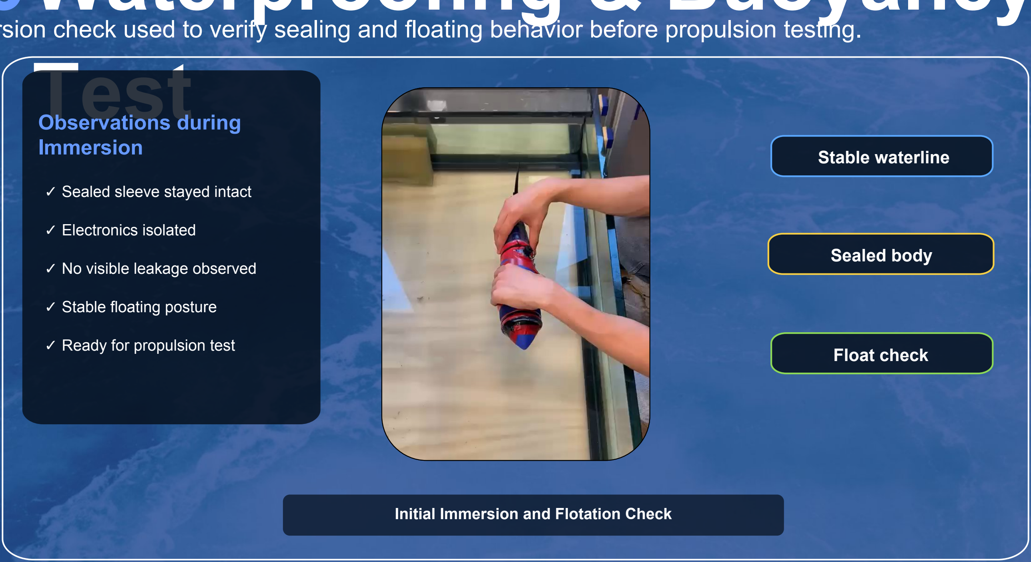
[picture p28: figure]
Test; Observations during Immersion; Initial Immersion and Flotation Check; Stable waterline; Sealed body; Float check; ✓ Sealed sleeve stayed intact ✓ Electronics isolated ✓ No visible leakage observed ✓ Stable floating posture ✓ Ready for propulsion test

Immersion check used to verify sealing and floating behavior before propulsion testing.

41

01 | 02 | 03 | 04 | 05

# Initial In-Water Trial: Caudal

o6

06

Test objective

- Observe body stability in water
- Check if tail oscillation produced forward motion
- Identify rolling/yawing behavior without side fins
Observation
- Slow forward motion was generated
- Directional stability was limited
- Missing fins affected balance and straight-line motion

Design insight
Side fins were needed to improve passive stability before final swimming tests.

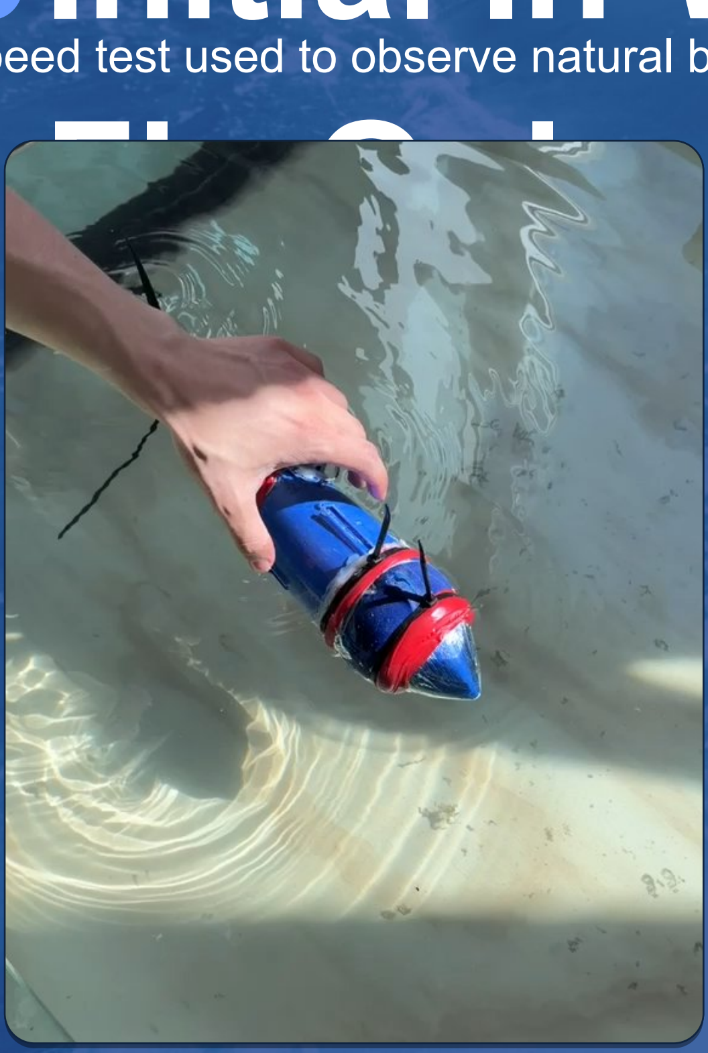
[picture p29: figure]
Fin Only

Low-speed test used to observe natural body response before adding stabilizing fins.

o6

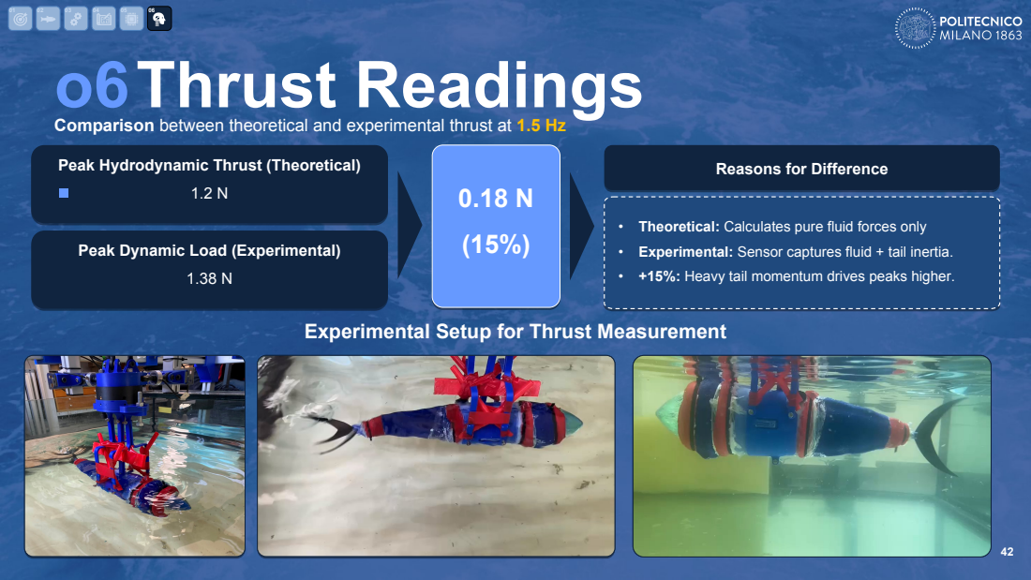
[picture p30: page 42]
Peak Dynamic Load (Experimental)

Thrust Readings Comparison between theoretical and experimental thrust at 1.5 Hz

Peak Hydrodynamic Thrust (Theoretical)

Reasons for Difference

• Theoretical: Calculates pure fluid forces only
• Experimental: Sensor captures fluid + tail inertia.
• +15%: Heavy tail momentum drives peaks higher.

Experimental Setup for Thrust Measurement

43

# Final In-Water Swimming Test

The fish was deployed in a testing tank and successfully completed its straight-line swimming goal.

o6

44

# Thank you for your attention

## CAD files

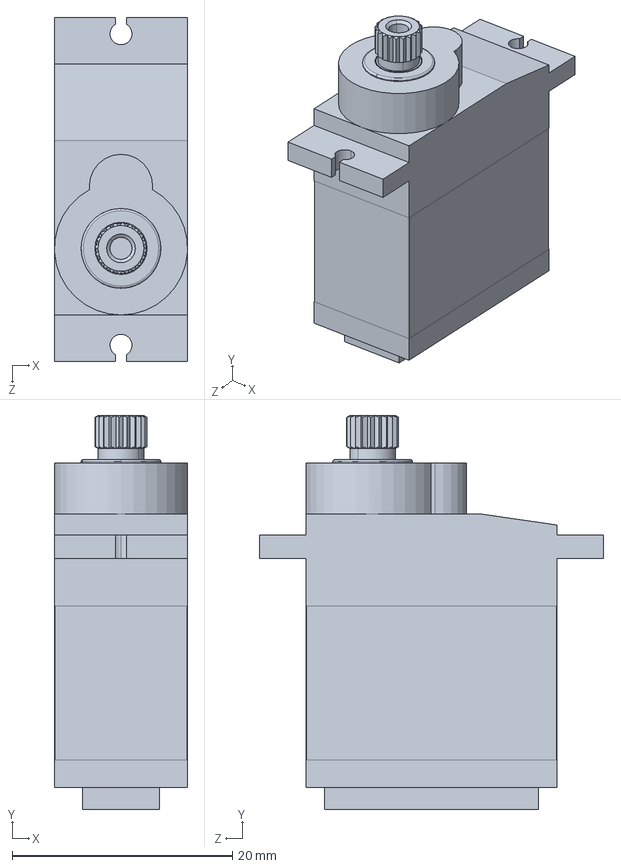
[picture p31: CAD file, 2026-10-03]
P.H.O.E.N.I.X_CAD/MG92B.SLDPRT
12.1 x 35.8 x 31.3 mm

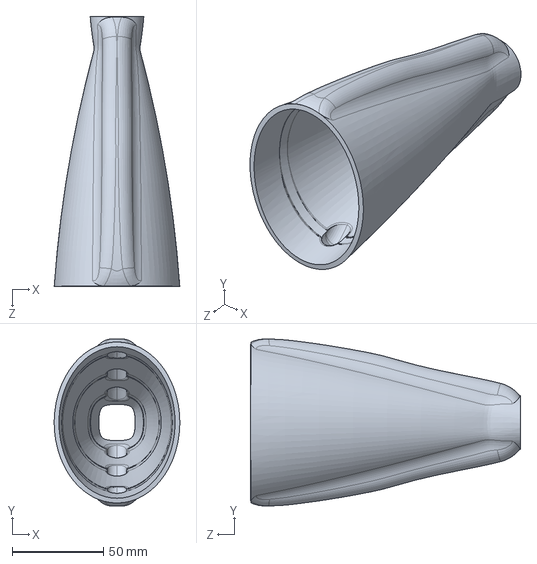
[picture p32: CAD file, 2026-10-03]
P.H.O.E.N.I.X_CAD/Sleeve_Final.SLDPRT
68.8 x 91.4 x 148.0 mm

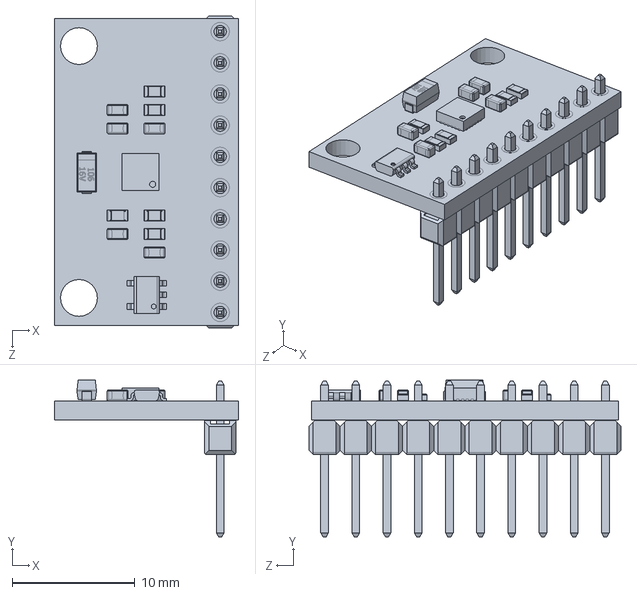
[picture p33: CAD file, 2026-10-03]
P.H.O.E.N.I.X_CAD/MPU-9250.SLDPRT
15.0 x 12.8 x 25.4 mm

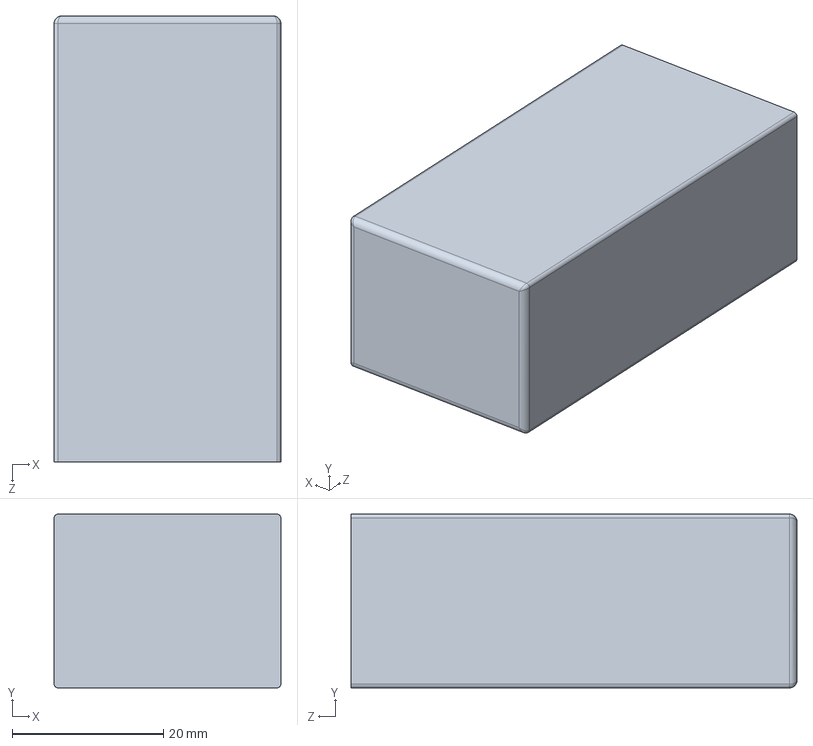
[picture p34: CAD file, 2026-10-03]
P.H.O.E.N.I.X_CAD/Ovonic_850mAh.SLDPRT
30.0 x 23.0 x 59.0 mm

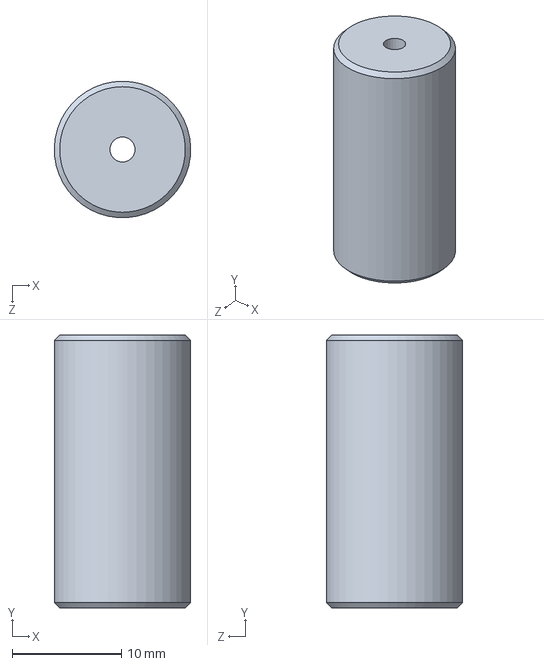
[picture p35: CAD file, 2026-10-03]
P.H.O.E.N.I.X_CAD/Rigid_Coupler_2.3_4.SLDPRT
12.5 x 25.0 x 12.5 mm

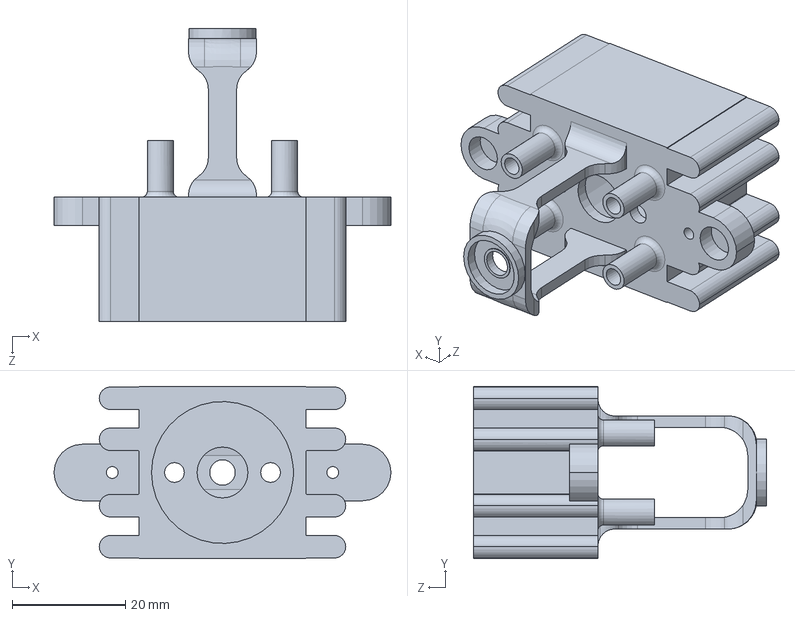
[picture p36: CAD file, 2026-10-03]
P.H.O.E.N.I.X_CAD/Motor_housing.SLDPRT
59.6 x 30.5 x 51.8 mm

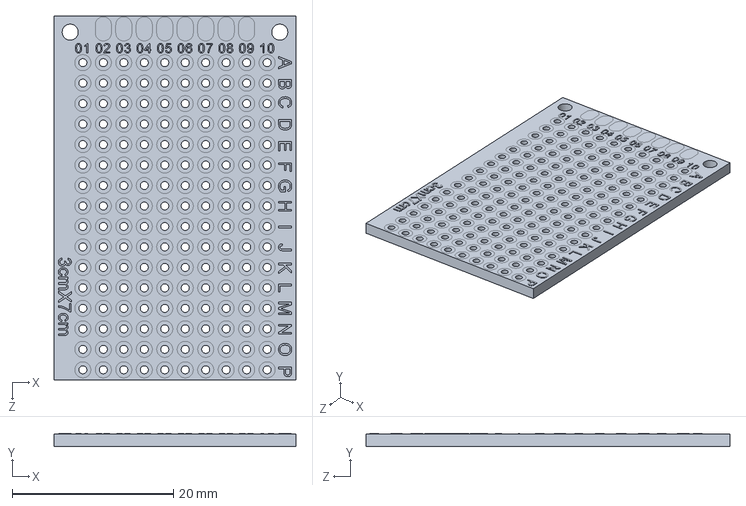
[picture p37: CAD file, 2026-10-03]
P.H.O.E.N.I.X_CAD/PCB_30x70.SLDPRT
30.0 x 1.65 x 45.2 mm

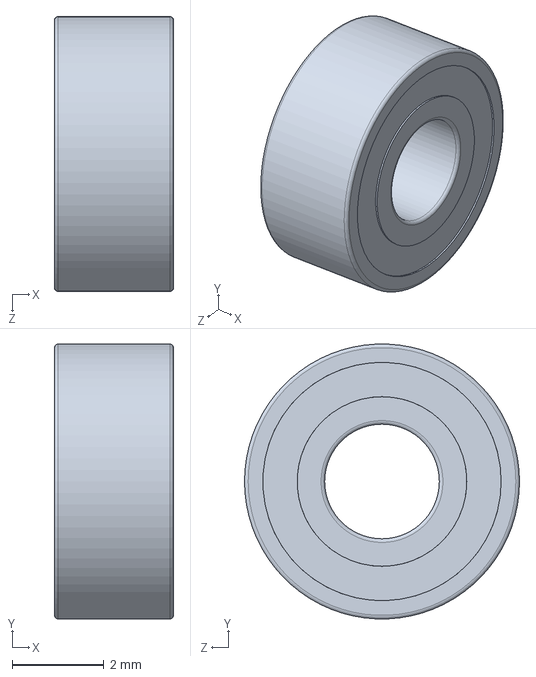
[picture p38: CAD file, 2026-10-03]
P.H.O.E.N.I.X_CAD/NSK_682XZZ.SLDPRT
2.60 x 5.99 x 6.00 mm

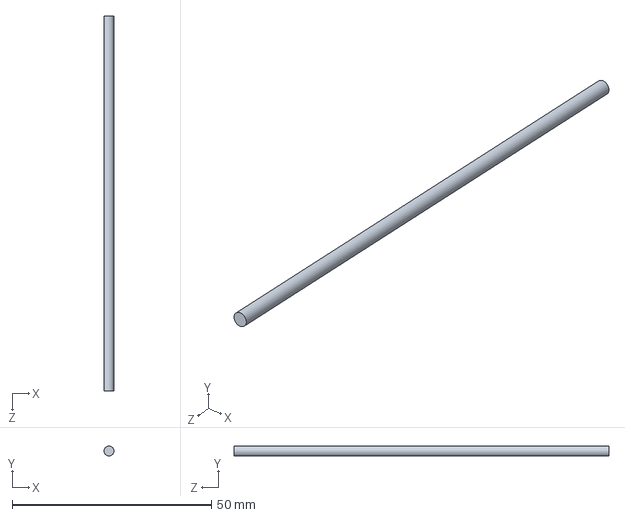
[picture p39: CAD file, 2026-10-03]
P.H.O.E.N.I.X_CAD/Spar_V2.SLDPRT
2.50 x 2.48 x 94.0 mm

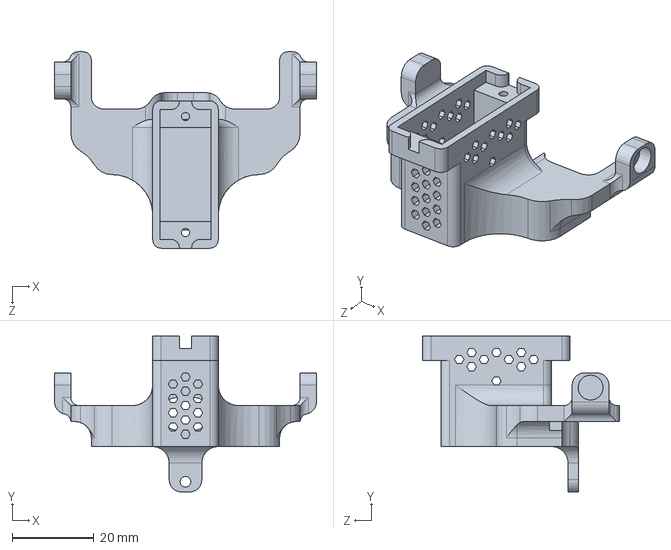
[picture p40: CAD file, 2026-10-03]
P.H.O.E.N.I.X_CAD/Servo_Housing.SLDPRT
64.0 x 38.1 x 48.0 mm

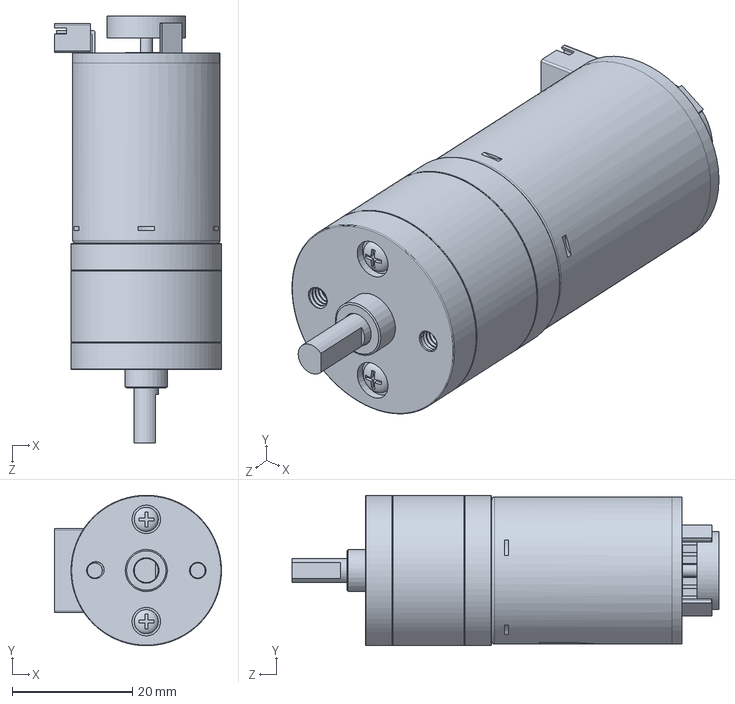
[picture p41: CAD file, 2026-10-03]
P.H.O.E.N.I.X_CAD/GM25-370.SLDPRT
27.8 x 25.0 x 70.9 mm

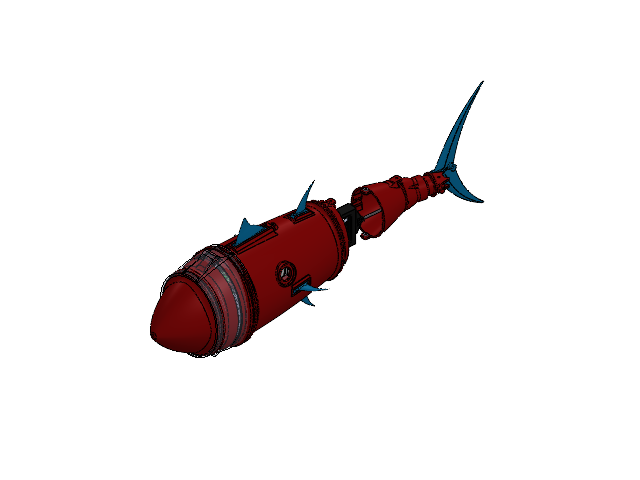
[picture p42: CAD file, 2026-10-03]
P.H.O.E.N.I.X_CAD/Tail_Links_Assembly.SLDASM
Link4
M2_Washer x 18
Spar_V2
Caudal_Fin_ABS_V2
GM25-370
Motor_housing
Rigid_Coupler_2.3_4
Flapper_V2
BAL-MF52ZZ x 2
Carbon_Fiber_Pin x 2
Flapper_Hinge_Stopper x 2
NSK_682XZZ x 2
Shaft_Bearing_Cap
hex nut style 1_am x 2
Servo_Housing
MG92B
Fin_Dorsal_v2
Dorsal_Fin_Stopper
Fin_Anal x 2
Fin_Lateral x 2
Battery_Housing
Ovonic_850mAh
Battery_Housing_Cover
DRV8871_MPU9250_Housing
MPU-9250 x 2
DRV8871_module v2
DRV8871_MPU9250_Housing_Cover
Ardiuno_Housing_V2
PCB_30x70
Arduino Nano_pbs_simplified
Head
9SENHMS
Head_Sleeve
Bent_Elbow
Link5_V3

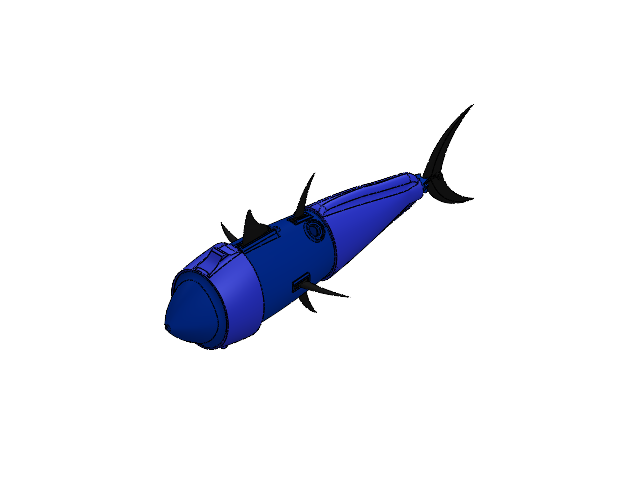
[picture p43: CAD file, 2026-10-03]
P.H.O.E.N.I.X_CAD/P.H.O.E.N.I.X.SLDASM
Body_V3
Motor_housing
Rigid_Coupler_2.3_4
Battery_Housing
Ovonic_850mAh
Battery_Housing_Cover
DRV8871_MPU9250_Housing
MPU-9250 x 2
DRV8871_module v2
DRV8871_MPU9250_Housing_Cover
Ardiuno_Housing_V2
PCB_30x70
Arduino Nano_pbs_simplified
Ardunio_Housing_Cover_V2
Servo_Housing
Head_V2
Fin_Anal_Bigger x 2
Fin_Dorsal_v2_Bigger
Fin_Lateral_Bigger x 2
Flapper_Hub
Flapper_V2
BAL-MF52ZZ x 2
NSK_682XZZ x 2
Flapper_Hinge_Stopper x 2
Spar_V2
Bent_Elbow
GM25-370
Link3
Link4
Link5_V3
Caudal_Fin_ABS_V3
Sleeve_Final
Head_Sleeve
MG92B

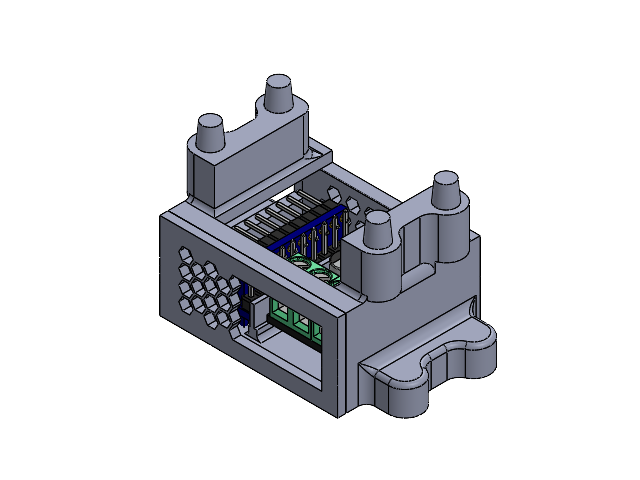
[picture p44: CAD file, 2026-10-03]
P.H.O.E.N.I.X_CAD/Assembled_DRV8871_MPU9250_Housing.SLDASM
DRV8871_MPU9250_Housing
MPU-9250 x 2
DRV8871_module v2
DRV8871_MPU9250_Housing_Cover

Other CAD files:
P.H.O.E.N.I.X_CAD/PCB_Ardiuno.SLDASM
P.H.O.E.N.I.X_CAD/Assembled_Arduino_PCB_Housing_V2.SLDASM
P.H.O.E.N.I.X_CAD/Assmebled_Battery_Housing.SLDASM
P.H.O.E.N.I.X_CAD/Assmebled_Electronics_Housing_V3.SLDASM
P.H.O.E.N.I.X_CAD/Ardiuno_Housing_V2.SLDPRT
P.H.O.E.N.I.X_CAD/Arduino Nano_pbs_simplified.SLDPRT
P.H.O.E.N.I.X_CAD/Ardunio_Housing_Cover_V2.SLDPRT
P.H.O.E.N.I.X_CAD/BAL-MF52ZZ.SLDPRT
P.H.O.E.N.I.X_CAD/Battery_Housing.SLDPRT
P.H.O.E.N.I.X_CAD/Battery_Housing_Cover.SLDPRT
P.H.O.E.N.I.X_CAD/Bent_Elbow.SLDPRT
P.H.O.E.N.I.X_CAD/Body_V3.SLDPRT
P.H.O.E.N.I.X_CAD/Caudal_Fin_ABS_V3.SLDPRT
P.H.O.E.N.I.X_CAD/DRV8871_MPU9250_Housing.SLDPRT
P.H.O.E.N.I.X_CAD/DRV8871_MPU9250_Housing_Cover.SLDPRT
P.H.O.E.N.I.X_CAD/DRV8871_module v2.SLDPRT
P.H.O.E.N.I.X_CAD/Fin_Anal_Bigger.SLDPRT
P.H.O.E.N.I.X_CAD/Fin_Dorsal_v2_Bigger.SLDPRT
P.H.O.E.N.I.X_CAD/Fin_Lateral_Bigger.SLDPRT
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

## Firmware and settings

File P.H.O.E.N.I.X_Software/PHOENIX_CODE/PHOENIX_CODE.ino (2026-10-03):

#include <util/atomic.h>
#include <Servo.h>
#include <Wire.h>
#include <MPU9250_asukiaaa.h>
#include <math.h>

//********* FEATURE TOGGLES *********//
// Change to toggle use of magnetic switch
bool useHallSensor = true;

// If actualSpeed becomes negative while the motor is spinning forward,
// change this from 1 to -1.
const int ENCODER_SIGN = 1;

//********* PIN CONFIGURATION *********//
const int IN1 = 5;       // DRV8871 PWM pin
const int IN2 = 6;       // DRV8871 Dir pin
const int encA = 2;      // Encoder Phase A
const int encB = 3;      // Encoder Phase B
const int hallPin = 4;   // A3144 Hall Effect Sensor
const int servoPin = 10; // Servo Signal Pin

//********* OBJECTS *********//
Servo headServo;
MPU9250_asukiaaa imu;

//********* SWIM SPEED VARIABLES *********//
float normalHz = 1.5; // Cruising Speed
float fastHz = 3.5;   // Sprint Speed
int currentMode = 0;  // 0 = OFF, 1 = NORMAL, 2 = FAST

//********* ENCODER VARIABLES *********//
volatile long encoderCount = 0;
long previousCount = 0;
float motorCPR = 374.0;  // 11 PPR x 34 Gear Ratio

//********* PID & RAMP VARIABLES *********//
unsigned long previousControlMillis = 0;
const long controlInterval = 50;  // ms

float currentTargetSpeed = 0.0;
float maxTargetSpeed = 0.0;
float rampRate = 1.0;  // encoder counts per control interval

float Kp = 1.5;
float Ki = 0.2;
float Kd = 0.1;

float integral = 0;
float previousError = 0;
float actualSpeed = 0;
int currentPWM = 0;

//********* HALL EFFECT VARIABLES *********//
unsigned long magnetStartTime = 0;
bool magnetPresent = false;
bool longPressTriggered = false;

//********* GYRO VARIABLES *********//
unsigned long previousGyroMillis = 0;
float angleX = 0.0f;
float gyroX_offset = 0.0f;

const float GYRO_MIN = -20.0f;   // Fish leans 20 degrees left
const float GYRO_MAX = 20.0f;    // Fish leans 20 degrees right
const float SERVO_MIN = 50.0f;   // Servo corrects right
const float SERVO_MAX = 90.0f;   // Servo corrects left
const int SERVO_CENTER = 70;

// ============================================================
//  HELPER FUNCTIONS
// ============================================================

long readEncoderCountSafe() {
  long countCopy = 0;

  ATOMIC_BLOCK(ATOMIC_RESTORESTATE) {
    countCopy = encoderCount;
  }

  return countCopy * ENCODER_SIGN;
}

void stopMotorImmediately() {
  currentPWM = 0;
  analogWrite(IN1, 0);
  digitalWrite(IN2, LOW);
}

void resetPID() {
  integral = 0;
  previousError = 0;
}

// ============================================================
//  SETUP
// ============================================================

void setup() {
  Serial.begin(115200);

  pinMode(IN1, OUTPUT);
  pinMode(IN2, OUTPUT);
  pinMode(encA, INPUT_PULLUP);
  pinMode(encB, INPUT_PULLUP);
  pinMode(hallPin, INPUT_PULLUP);

  attachInterrupt(digitalPinToInterrupt(encA), updateEncoder, RISING);

  digitalWrite(IN2, LOW);
  stopMotorImmediately();

  // Init Servo
  headServo.attach(servoPin);
  headServo.write(SERVO_CENTER);

  // Init Gyro
  Wire.begin();
  imu.setWire(&Wire);
  imu.beginGyro();

  delay(100);
  calibrateGyro();

  previousGyroMillis = millis();
  previousControlMillis = millis();
  previousCount = readEncoderCountSafe();

  // Handle the "Bypass Sensor" Feature
  if (!useHallSensor) {
    Serial.println("Hall Sensor Bypassed. Auto-Starting NORMAL Mode.");
    setSwimMode(1);
  } else {
    Serial.println("Awaiting Magnetic Scan...");
  }
}

// ============================================================
//  MAIN LOOP
// ============================================================

void loop() {
  unsigned long currentMillis = millis();

  // 1. Read the UI using Hall Effect Sensor
  if (useHallSensor) {
    runHallSensor();
  }

  // 2. Head Stabilization every 10 ms
  if (currentMillis - previousGyroMillis >= 10) {
    runGyroServo(currentMillis);
  }

  // 3. Motor PID & Soft-Start every 50 ms
  if (currentMillis - previousControlMillis >= controlInterval) {
    runMotorControl(currentMillis);
  }
}

// ============================================================
//  HALL EFFECT LOGIC
// ============================================================

void runHallSensor() {
  int hallState = digitalRead(hallPin);

  if (hallState == LOW) {
    // Magnet is touching
    if (!magnetPresent) {
      magnetPresent = true;
      magnetStartTime = millis();
      longPressTriggered = false;
    } else {
      // Magnet is being held down. Wait for 3 seconds.
      if (!longPressTriggered && (millis() - magnetStartTime >= 3000)) {
        longPressTriggered = true;
        setSwimMode(2); // FAST MODE
        Serial.println("LONG PRESS: Fast Mode Engaged!");
      }
    }
  } else {
    // Magnet was removed
    if (magnetPresent) {
      magnetPresent = false;
      unsigned long holdTime = millis() - magnetStartTime;

      // Short tap: more than 50 ms but less than 3 seconds
      if (!longPressTriggered && holdTime > 50) {
        if (currentMode == 0) {
          setSwimMode(1); // Turn ON Normal Mode
          Serial.println("SHORT TAP: Normal Mode Engaged!");
        } else {
          setSwimMode(0); // Turn OFF
          Serial.println("SHORT TAP: Motor Stopped.");
        }
      }
    }
  }
}

// ============================================================
//  SET SPEED TARGETS
// ============================================================

void setSwimMode(int mode) {
  currentMode = mode;

  // OFF mode: stop immediately, do not wait for ramp-down
  if (mode == 0) {
    maxTargetSpeed = 0.0;
    currentTargetSpeed = 0.0;
    resetPID();
    stopMotorImmediately();
    previousCount = readEncoderCountSafe();
    return;
  }

  resetPID();
  currentTargetSpeed = 0.0; // Clear previous ramp memory to start smoothly from 0
  previousCount = readEncoderCountSafe();

  float targetHz = 0.0;

  if (mode == 1) {
    targetHz = normalHz;
  } else if (mode == 2) {
    targetHz = fastHz;
  }

  // Explicit float-safe conversion from milliseconds to seconds
  float controlIntervalSeconds = (float)controlInterval / 1000.0f;

  // Target speed = expected encoder counts per control interval
  maxTargetSpeed = targetHz * motorCPR * controlIntervalSeconds;
}

// ============================================================
//  MOTOR PID & SOFT START
// ============================================================

void runMotorControl(unsigned long currentMillis) {
  previousControlMillis = currentMillis;

  // Safety: if OFF, force motor to stay stopped
  if (currentMode == 0) {
    currentTargetSpeed = 0.0;
    maxTargetSpeed = 0.0;
    resetPID();
    stopMotorImmediately();
    previousCount = readEncoderCountSafe();
    return;
  }

  // A. RAMP UP or RAMP DOWN
  if (currentTargetSpeed < maxTargetSpeed) {
    currentTargetSpeed += rampRate;
    if (currentTargetSpeed > maxTargetSpeed) {
      currentTargetSpeed = maxTargetSpeed;
    }
  } else if (currentTargetSpeed > maxTargetSpeed) {
    currentTargetSpeed -= rampRate;
    if (currentTargetSpeed < maxTargetSpeed) {
      currentTargetSpeed = maxTargetSpeed;
    }
  }

  // B. READ ENCODER SAFELY
  long currentCount = readEncoderCountSafe();

  actualSpeed = currentCount - previousCount;
  previousCount = currentCount;

  // C. PID MATH
  float error = currentTargetSpeed - actualSpeed;

  integral += error;

  // Anti-windup limit
  if (integral > 200) {
    integral = 200;
  }

  if (integral < -200) {
    integral = -200;
  }

  float derivative = error - previousError;
  previousError = error;

  float controlSignal = (Kp * error) + (Ki * integral) + (Kd * derivative);

  // D. APPLY POWER
  currentPWM = (int)constrain(controlSignal, 0.0f, 255.0f);

  digitalWrite(IN2, LOW);
  analogWrite(IN1, currentPWM);
}

// ============================================================
//  GYROSCOPE HEAD STABILIZATION
// ============================================================

void runGyroServo(unsigned long currentMillis) {
  float dt = (currentMillis - previousGyroMillis) / 1000.0f;
  previousGyroMillis = currentMillis;

  imu.gyroUpdate();

  float gx = imu.gyroX() - gyroX_offset;

  // Deadzone: ignore micro-vibrations
  if (fabs(gx) < 0.5f) {
    gx = 0.0f;
  }

  // Integrate gyro velocity to estimate angle
  angleX += gx * dt;

  // Leaky integrator: pulls the integrated angle slowly back toward 0.
  // This prevents tracking drift and keeps the physical response responsive.
  angleX *= 0.95f; 

  // Clamp the calculated angle to stay within defined boundaries
  float clampedAngle = constrain(angleX, GYRO_MIN, GYRO_MAX);

  // Float-safe servo mapping processing
  // If correction is reversed, swap SERVO_MAX and SERVO_MIN in this formula.
  float servoFloat = SERVO_MAX + 
    ((clampedAngle - GYRO_MIN) * (SERVO_MIN - SERVO_MAX)) / 
    (GYRO_MAX - GYRO_MIN);

  int servoPos = (int)(servoFloat + 0.5f);
  servoPos = constrain(servoPos, (int)SERVO_MIN, (int)SERVO_MAX);

  headServo.write(servoPos);
}

// ============================================================
//  CALIBRATE GYROSCOPE
// ============================================================

void calibrateGyro() {
  Serial.println("Calibrating Gyro... KEEP SENSOR STILL.");

  float sum = 0.0f;

  for (int i = 0; i < 500; i++) {
    imu.gyroUpdate();
    sum += imu.gyroX();
    delay(4);
  }

  gyroX_offset = sum / 500.0f;
  angleX = 0.0f;

  Serial.println("Calibration Complete.");
}

// ============================================================
//  ENCODER INTERRUPT
// ============================================================

void updateEncoder() {
  if (digitalRead(encB) == HIGH) {
    encoderCount++;
  } else {
    encoderCount--;
  }
}

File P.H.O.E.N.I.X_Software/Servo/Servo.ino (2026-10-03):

#include <Servo.h> 

//********* PIN & OBJECT CONFIGURATION *********//
const int headServoPin = 9; 
Servo headServo; 

//********* SWEEP VARIABLES *********//
int centerAngle = 95; // This is your physical "Zero" straight ahead
int sweepAngle = 15;  // Scans 15 degrees left and 15 degrees right
int currentAngle = 95; 

// Tuning: A higher number makes the head turn slower and more naturally.
// 25ms is a good, slow "looking around" speed.
int scanDelay = 50; 

void setup() {
  headServo.attach(headServoPin);

  // Instantly lock the servo to the middle (90 degrees).
  // DO THIS BEFORE ATTACHING THE HEAD!
  headServo.write(centerAngle);
  delay(2000); // Give you 2 seconds to see it lock in place
}

void loop() {
  // --- SCAN LEFT ---
  // Move from 75 to 105 degrees smoothly
  for (currentAngle = (centerAngle - sweepAngle); currentAngle <= (centerAngle + sweepAngle); currentAngle++) { 
    headServo.write(currentAngle);              
    delay(scanDelay);                      
  }
  
  // --- SCAN RIGHT ---
  // Move from 105 back down to 75 degrees smoothly
  for (currentAngle = (centerAngle + sweepAngle); currentAngle >= (centerAngle - sweepAngle); currentAngle--) { 
    headServo.write(currentAngle);              
    delay(scanDelay);                       
  }
}
